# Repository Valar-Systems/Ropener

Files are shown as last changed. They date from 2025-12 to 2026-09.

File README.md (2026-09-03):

# The Ropener: Silent drape runners

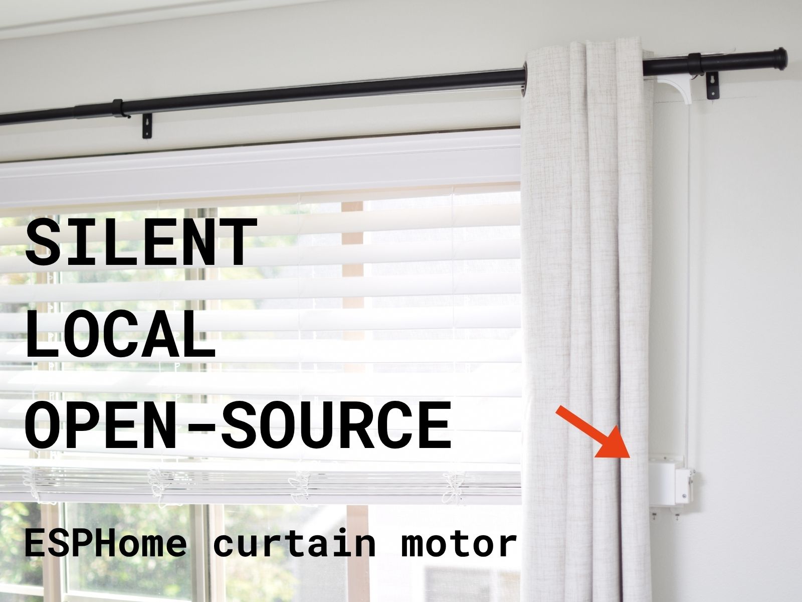
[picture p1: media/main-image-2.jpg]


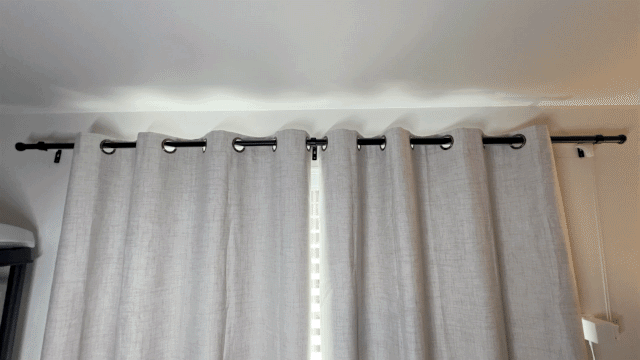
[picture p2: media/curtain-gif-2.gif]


Thanks for the great idea, Nadine!

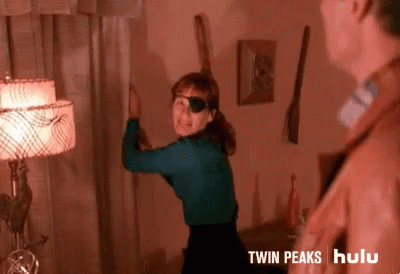
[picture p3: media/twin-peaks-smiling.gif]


The Ropener is a smart curtain opener that uses two buttons and ESPHome to open and close your curtain. Combine it with Node-RED, Home Assistant (via ESPhome) to get your curtain to open and close automatically.

## Kits
This device was created by me, [Daniel Frenkel](https://github.com/daniel-frenkel), and I have a small US-based shop that you can purchase a [hardware kit](https://valarsystems.com/products/ropener) from. If it's sold out, **PLEASE** sign up to the waitlist. It's the only indication I have to make more. If you don't, then I'll **NEVER** make more.

Without the kit, it's a pain to source all the parts, and costs a lot more because you'll be forced to buy 100 screws (when you only need 2) and 100ft of rope (when you only need 30ft) at a time.

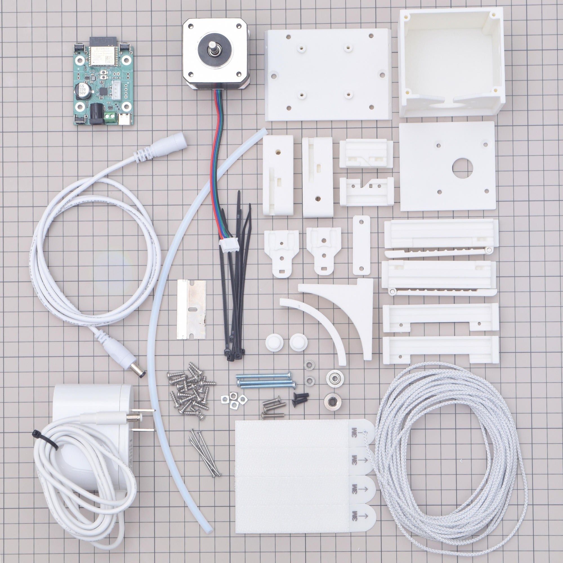
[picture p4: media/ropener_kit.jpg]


## How it works

The motor is attached to your wall just behind one of the curtains

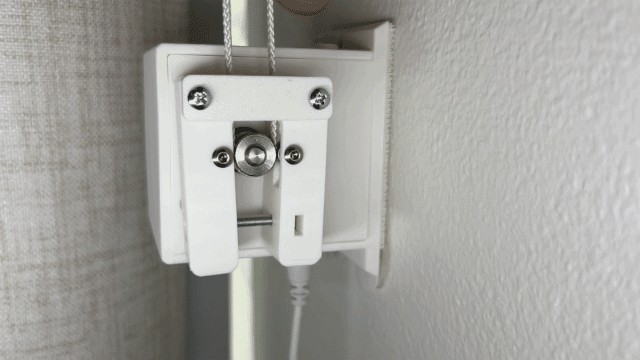
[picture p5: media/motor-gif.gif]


There is a carriage attached to the back of each curtain panel. A string runs through each carriage and through the motor which pulls it open and close.

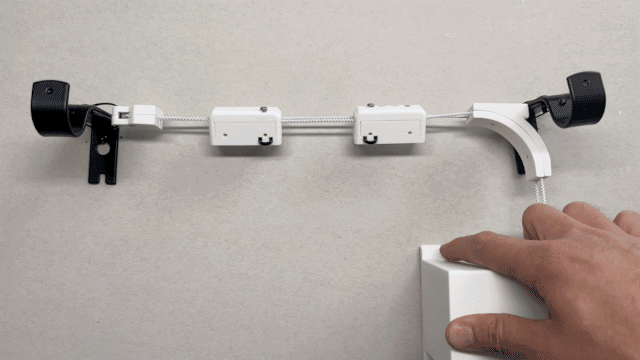
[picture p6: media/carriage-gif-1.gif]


At the heart of the device is our custom PCB which uses an ESP32 and Trinamic TMC2209 stepper driver. The motor is dead silent.

The latest **v1.1** hardware revision uses a smaller-diameter MK8 drive gear that boosts the pull strength from 11 lb to **15 lb**, swaps to a single larger bearing per arm (fewer parts), and uses pre-cut PTFE tubes. See the [hardware notes](hardware/README.md) for details.

## Will it work on your curtains?

This works on the following curtains:

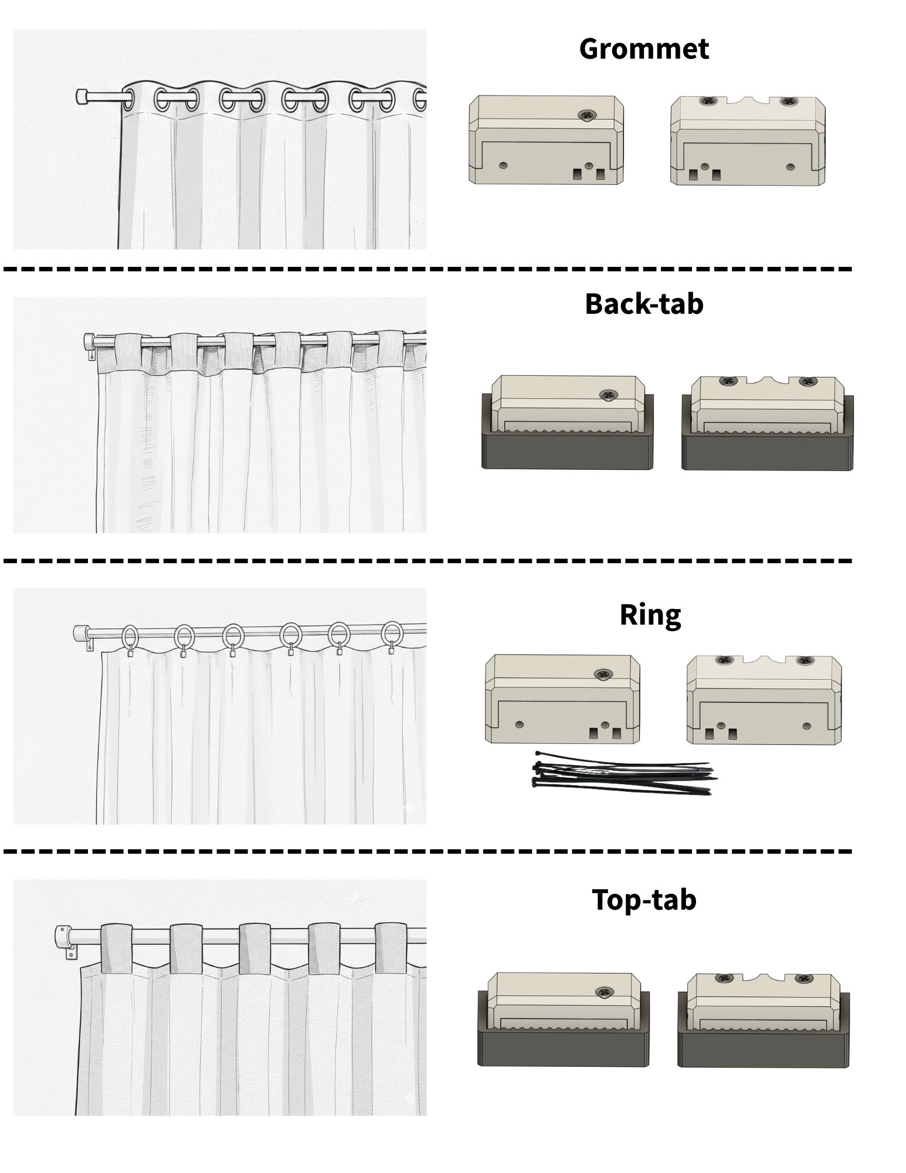
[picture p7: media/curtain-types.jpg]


## How to build it

The build guide can be found [here](https://youtu.be/uowt6jLxNso).

The installation guide can be found [here](https://youtu.be/p8078ezLZHw).

We've created a hardware kit that includes everything. If you source the parts individually, it will cost 5X more just because all of the hardware need to purchased in bulk from places like McMaster-Carr. You may optionally 3D print your parts.

* Total print time: ~9 hours (You can also purchase the 3D prints)
* Total assembly time: ~20 minutes

[Link to kit](https://valarsystems.com/products/ropener)

## How to 3D print it

The current revision is **v1.1**. Open the print plate at [hardware/plastics/v1.1/platter-all-v1.1.3mf](hardware/plastics/v1.1/platter-all-v1.1.3mf), or print the individual `.step` files in that folder. The earlier [v1.0](hardware/plastics/v1.0) files remain for anyone who already built one.

## How to install it

Either use the included foam mounting squares (recommended), small nails (for drywall only), or two screws/anchors. It's very easy to install.

## Sending commands

ESPHome is the preferred way of controlling it. Pair it with Matterbridge and you can control your curtains with Alexa, Apple, and Google Home.

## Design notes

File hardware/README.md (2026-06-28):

# What's new in v1.1
The current hardware revision is **v1.1**. Print from [`hardware/plastics/v1.1`](plastics/v1.1) (the [v1.0](plastics/v1.0) files remain for anyone who already built one).

- **Stronger pull (11 lb → 15 lb)** — a smaller-diameter **MK8** drive gear replaces the MK7.
- **Fewer parts** — each arm now uses **one larger 633ZZ bearing (3 × 13 × 5 mm)** instead of two small bearings.
- **Pre-cut PTFE tubes** — tubes now ship pre-cut to **10 / 40 / 70 mm** (two of each), so there's no measuring or razor-cutting during the build.

The plastics changed slightly to suit the new tube lengths; otherwise assembly is the same.

# Instructions
Image build guide can be found [here](https://canva.link/tmpoyau5pfkddx3).\
Video build guide can be found [here](https://youtu.be/uowt6jLxNso).\
Video installation guide can be found [here](https://youtu.be/p8078ezLZHw).

# Parts
You can purchase a kit [here](https://valarsystems.com/products/ropener) that includes all of these parts.\
Or you can source the parts below.

| Item  | Quantity|
| ---|---|
| [PCB](https://valarsystems.com/products/val3000)|1|
| [Motor](https://valarsystems.com/products/stepper-motor-nema-17)|1|
| [24V 1.5A Power adapter](https://valarsystems.com/products/power-adapter)|1|
| [Cable extension](https://valarsystems.com/products/barrel-plug-extension-cable?variant=43389605609531)|As needed|
| [3M Command Strips](https://valarsystems.com/products/3m-command-strips)|4|
| [Rope](https://valarsystems.com/products/rope)|30ft|
| [PTFE Tubing (pre-cut: 2×10mm, 2×40mm, 2×70mm)](https://valarsystems.com/products/ptfe-tube)|6|
| [M3 Square Nut](https://valarsystems.com/products/m3-square-nut)|4|
| [M3x35mm Button Head Screw](https://valarsystems.com/products/m3-x-35mm-button-head-screw)|3|
| [V-Groove Pulley](https://valarsystems.com/products/v-groove-pulley)|1|
| [M3x10mm Flat Head Screw](https://valarsystems.com/products/m3-x-35mm-button-head-screw-copy)|2|
| [M3x15mm Button Head Screw](https://valarsystems.com/products/m3-x-10mm-thread-forming-screw-copy)|3|
| [633ZZ Bearing (3×13×5mm)](https://valarsystems.com/products/bearing)|2|
| [MK8 Drive Gear](https://valarsystems.com/products/ropener-drive-gear)|1|
| [Zip Tie](https://valarsystems.com/products/zip-tie)|4|
| [M3x10mm Thread Forming Screw](https://valarsystems.com/products/m3-x-10mm-thread-forming-screw)|23|

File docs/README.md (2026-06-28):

# Docs

This folder holds the **sources** for the Ropener documentation and the scripts
that render them. The rendered deliverables (`.docx` / `.pdf` / `.png`) are
**generated artifacts** — they are written to `dist/` and are **not** tracked in
git (see the root `.gitignore`). The print-ready finals are published to the
Valar Systems Google Drive, the same way firmware binaries go to GitHub Releases.

## What's tracked (source)

| File | Role |
| --- | --- |
| `BOM-V2.0.md` | Bill of Materials, human-readable source (also linked from the wiki) |
| `Ropener-User-Guide.md` | Markdown copy of the user guide |
| `make_bom.py` | Renders the BOM `.docx` |
| `make_box_insert.py` | Renders the box-insert `.png` + `.pdf` |
| `make_user_guide.py` | Renders the user-guide `.docx` |
| `valar-logo-black.png`, `valar-logo-white.png` | Brand assets used by the generators |
| `wiki-*.md` | Mirror of the GitHub wiki pages |

## What's generated (in `dist/`, gitignored)

- `Ropener Bill of Materials.docx`
- `Ropener Box Insert.png` / `Ropener Box Insert.pdf`
- `Ropener User Guide.docx`
- `Ropener Bill of Materials.pdf`, `Ropener User Guide.pdf` (see Word step below)

## Regenerating

```sh
pip install python-docx pillow segno      # one-time
py -3.13 make_bom.py
py -3.13 make_box_insert.py
py -3.13 make_user_guide.py
```

Each script writes into `dist/`.

- **Box insert** is fully reproducible on any platform — the script emits both
  the `.png` and the `.pdf` directly.
- **BOM** and **User Guide** scripts emit only `.docx`. To produce the matching
  `.pdf`, open the `.docx` in **Microsoft Word** and *Save As → PDF* (requires
  Windows + Word; this step is not reproducible in CI).

Then upload the finals from `dist/` to the Valar Drive.

## Known caveat

The user-guide content currently lives in **two** places: inline in
`make_user_guide.py` and again in `Ropener-User-Guide.md`; `make_bom.py`
likewise duplicates `BOM-V2.0.md` by hand. Keep them in sync when editing. The
proper long-term fix is to have the generators read the markdown directly so
there is a single source of truth.

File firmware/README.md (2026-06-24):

# ESPHome YAML

#### Warning:
***Do not use StallGuard*** unless you set it up correctly. StallGuard is finicky and requires exact parameters. I am working on creating preset settings that should fix this, but for now, do not use it. It is also not required for this device to work properly.

After pasting the YAML into ESPHome, ***only*** change the device names. Do not change anything else.

```
esphome:
  name: ropener-bedroom-1                 # change this name
  friendly_name: "Ropener Bedroom 1"      # change this name
```

After uploading, go to the settings page here and update the things in red.

settings

The most important settings are the centimeters (this sets the max travel distance) and the motor direction.

IRUN sets the motor current. 31 is the max value. The downside of a higher setting is that the driver will heat up quickly and will shut down when too hot. Use as low of a value as possible. A value too low however will make the motor too weak and it will stall. It's best to experiment to find the lowest value possible while not stalling the motor. Stalling does not damage the motor.

Be sure the state is correct in the settings when the device is moving.

state

Once everything is set, you have to manually set the home position. There are 3 ways to do this.

1. In the settings, under Diagnostic, there is a "Start-Stop Homing" button. Press it and it will begin to close the curtain. Press it again to stop the curtain. This will now be the zero position.
2. Tap the left button (Button 1) on the motor **seven times quickly**. It will begin to close the curtain. Press either button once to stop it — this stops the motor and sets the position to zero.
3. Move the curtain to the spot you want to call "closed" (use hold-to-run, below), then **hold both buttons at once for 3 seconds**. The current position is set as home (0) without driving into the end stop.

It should now be homed to position 0, and when you press the open button, it should travel the centimeters distance you set in the settings.

## Button controls

| Gesture | Action |
| --- | --- |
| Tap Button 1 (close) | Close the curtain |
| Tap Button 2 (open) | Open the curtain |
| Press & hold Button 1 | Close **only while held** — stops the instant you let go, and stops automatically at the closed end |
| Press & hold Button 2 | Open **only while held** — stops the instant you let go, and stops automatically at the open end |
| Tap Button 1 seven times quickly | Start homing |
| Hold both buttons for 3 seconds | Set the current position as home (0) |
| Any press while the curtain is moving | Stops it instantly |
| Any press while homing | Stops it and sets the position to zero |

Hold-to-run is the child- and elderly-friendly mode: the curtain only moves while you keep the button pressed, so it can't run on its own into a person or a cord, and it never drives past the open or closed ends.

## Updating the firmware

Two ways to update:

- **Over the air, from the device:** open the settings page and, under Diagnostics, press **"Update Firmware (GitHub)"**. The device downloads the latest release for its model straight from GitHub, flashes itself, and reboots — no computer needed. (Requires an internet connection.)
- **Manually:** download the `*.ota.bin` (for a device already on your network) or `*.factory.bin` (for a fresh USB flash) for your model from the [latest release](https://github.com/Valar-Systems/Ropener/releases/latest) and upload it as before.

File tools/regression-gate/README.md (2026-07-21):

# Firmware regression gate

Two diffs between the **old** and **new** resolved firmware config. Run both
before every release. A clean `esphome compile` is necessary but **not
sufficient** — it proves the YAML is valid, not that the firmware still behaves
the same.

## Why the behaviour gate exists

v2.7.0 rewired the Ropener onto `valar-core` as a remote package. The entity
gate passed perfectly: no entity dropped, renamed, or retyped. It shipped.

But the product's `on_stall` handler had been silently replaced by
`valar-core`'s default. Two live bugs resulted:

- the device wedged in `HOMING` forever after any home (killing the button
  gestures and the schedule, both of which guard on `global_state`), and
- **every** stall zeroed the position, so a curtain snagging mid-travel
  silently redefined that point as home.

No entity name changed, so nothing caught it. The behaviour gate diffs the
*automation bodies* — `on_stall`, `on_press`/`on_click`/`on_release`, script
bodies, `on_boot`, intervals, `*_action`, lambdas — anchored to stable
identities rather than list positions.

It also caught an unrelated change in the same release: the `Motor Direction`
option string `"Reversed ↺"` had lost its glyph, which would have broken any
Home Assistant automation selecting it by value.

## Usage

```sh
# 1. Resolve both configs (from a checkout of each version)
esphome config firmware/VAL3100/Ropener-VAL3100.yml > /tmp/old-3100.yaml
esphome config firmware/VAL3100/Ropener-VAL3100.yml > /tmp/new-3100.yaml

# 2. Diff them
python tools/regression-gate/gate.py /tmp/old-3100.yaml /tmp/new-3100.yaml

# 3. Inspect anything it flags
python tools/regression-gate/gate.py /tmp/old-3100.yaml /tmp/new-3100.yaml \
    --detail on_stall
```

Exit code `0` = both gates clean, `1` = something differs. **A difference is not
automatically a failure** — additions and refactors are often intended. The
gate's job is to guarantee nothing changes *unnoticed*. Every flagged line must
be explained in the release notes.

Run it for **each board** (VAL3000 and VAL3100); they share a product layer but
resolve differently.

Requires `pyyaml` — use the interpreter ESPHome is installed under.

## Known-benign differences after the valar-core rewire

Expected when diffing a pre-rewire release (≤ v2.6.4) against a rewired one:

| Anchor | Why |
|---|---|
| 7 diagnostic entities added | `valar-core` shared diagnostics (Restart, Uptime, WiFi Signal, ESP Internal Temperature, IP/SSID/MAC) |
| `esphome:on_boot` split 600 / 400 / -100 | core / product / scheduling layers; relative order preserved |
| `script:schedule_open`, `script:schedule_close` | scheduling-mixin contract; the `global_state != 3` homing guard moved into these scripts |
| `datetime:Open Time`/`Close Time` `on_time`, `interval:60s` | now call the schedule scripts instead of inlining `cover.open`/`cover.close` |

Anything **outside** this table needs justification before release.

## Before Glasscalibur

This tool should move to `valar-motion` so both products share one copy rather
than duplicating it — same rule as the firmware itself. Glasscalibur's overrides
(limit switches, TMP1075 thermal cutoff, LIS2DH12 tamper, buzzer) carry the same
silent-replacement risk as `on_stall` did here, and there a dropped thermal
cutoff or tamper handler is a safety regression, not a UX one.

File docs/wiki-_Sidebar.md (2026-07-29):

<p align="center">
  <a href="Home"><b>Ropener</b></a><br/>
  <a href="https://valarsystems.com/products/ropener">🛒 Buy a kit</a>
</p>

---

**Getting Started**
- [Home](Home)

**Build & Install**
- [Build Guide](Build-Guide)
- [Installation Guide](Installation-Guide)
- [Bill of Materials](https://github.com/Valar-Systems/Ropener/blob/main/docs/BOM-V2.0.md)

**Firmware & Use**
- [Firmware Guide](Firmware-Guide)
- [User Guide](User-Guide)

---

**Links**
- [GitHub Repo](https://github.com/Valar-Systems/Ropener)
- [Report an Issue](https://github.com/Valar-Systems/Ropener/issues)
- [valarsystems.com](https://valarsystems.com)

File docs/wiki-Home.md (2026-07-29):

<p align="center">
  Ropener automated curtain opener
</p>

<h1 align="center">Ropener</h1>
<p align="center"><b>The dead-silent Wi-Fi curtain opener.</b><br/>
Control it from its built-in web page, the on-device buttons, or your smart home (Home Assistant, Alexa, Apple Home, Google Home).</p>

<p align="center">
  <a href="https://valarsystems.com/products/ropener"><b>🛒 Buy a kit</b></a> &nbsp;·&nbsp;
  <a href="Build-Guide"><b>🔧 Build it</b></a> &nbsp;·&nbsp;
  <a href="User-Guide"><b>📖 User Guide</b></a>
</p>

---

## Quick Start

| Step | What you'll do | Guide |
| :--: | :--- | :--- |
| **1** | Get the parts — buy a kit or 3D-print the plastics. | [🛒 Kit](https://valarsystems.com/products/ropener) · [📋 BOM](https://github.com/Valar-Systems/Ropener/blob/main/docs/BOM-V2.0.md) |
| **2** | Build it (~20 min). | [Build Guide](Build-Guide) |
| **3** | Install it on your curtains. | [Installation Guide](Installation-Guide) |
| **4** | Flash & configure the firmware. | [Firmware Guide](Firmware-Guide) |
| **5** | Use it every day. | [User Guide](User-Guide) |

> 💬 Having trouble? [Open an issue](https://github.com/Valar-Systems/Ropener/issues) or improve this wiki.

---

## Why Ropener

- **🔇 Silent** — Trinamic TMC2209 stepper driver.
- **📶 Wi-Fi built in** — control from any browser at `http://ropener-XXXXXX.local`, no cloud needed.
- **🏠 Smart-home ready** — Home Assistant via ESPHome; Alexa, Apple & Google via Matterbridge.
- **⏰ Scheduling** — set daily open/close times, or any position in between.
- **🛠️ Easy install** — foam mounting squares mean no holes in the wall.

---

<p align="center">
  <a href="https://valarsystems.com">Valar Systems</a> · <a href="https://valarsystems.com/products/ropener">Buy a kit</a> · <a href="https://github.com/Valar-Systems/Ropener">Repo</a> · <a href="https://github.com/Valar-Systems/Ropener/issues">Issues</a>
</p>

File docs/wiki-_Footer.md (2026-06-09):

<p align="center">
  <a href="https://valarsystems.com"><b>Valar Systems</b></a> ·
  <a href="https://valarsystems.com/products/ropener">🛒 Buy a kit</a> ·
  <a href="https://github.com/Valar-Systems/Ropener">GitHub Repo</a> ·
  <a href="https://github.com/Valar-Systems/Ropener/issues">💬 Report an issue</a>
</p>

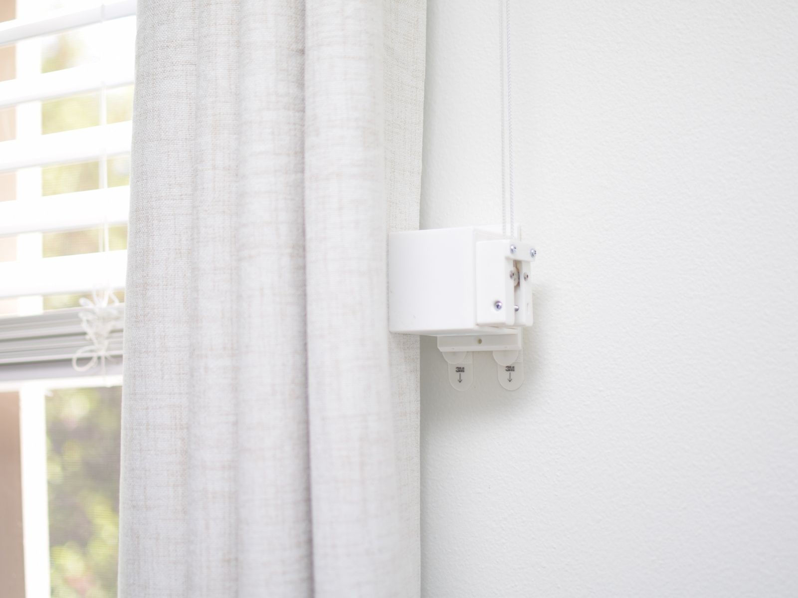
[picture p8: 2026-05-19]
media/ropener-closeup.jpg

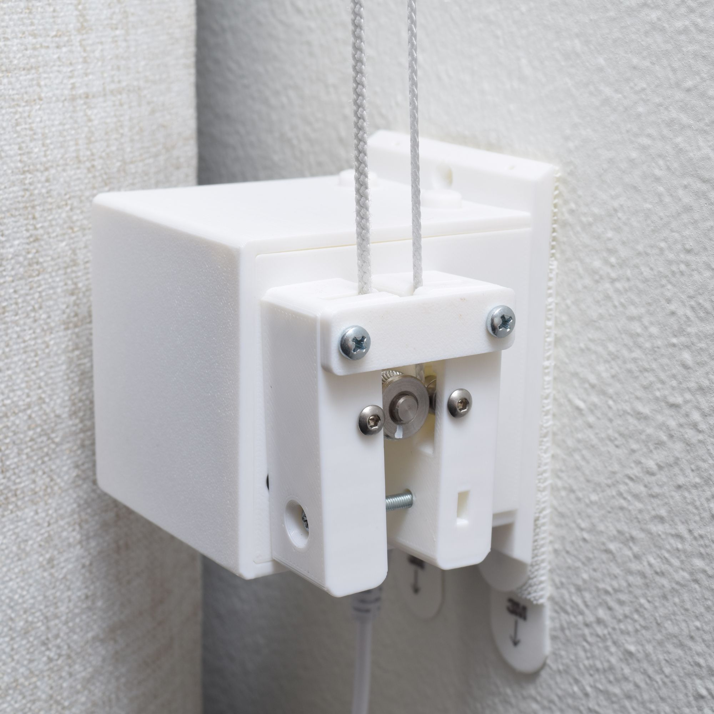
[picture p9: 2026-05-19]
media/ropener-closeup-2.jpg

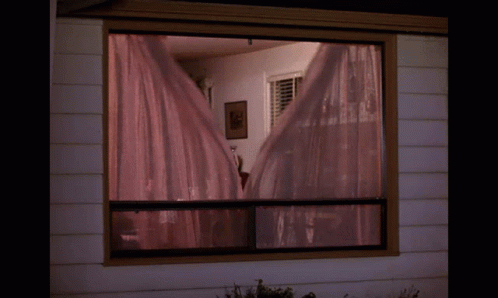
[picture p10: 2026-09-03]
media/twin-peaks-nadine-drapes.gif

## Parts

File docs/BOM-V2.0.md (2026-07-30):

# BOM V2.0

> Reflects the current **v1.2.1** hardware. Notable changes since v1.0: a smaller-diameter **MK8** drive gear (pull strength 11 lb → 15 lb), **one larger 633ZZ bearing per arm** instead of two small bearings, **pre-cut PTFE tubes** (no razor-cutting), **foam mounting squares** in place of adhesive command strips, and a **24 V 1.5 A** power adapter. Quantities are per unit. Every purchasable part links to the [Valar Systems store](https://valarsystems.com).

## Body Assembly

| Part | Qty | Description |
| :--- | :---: | :--- |
| VAL3000 PCB | 1 | [Custom ESP32 + Trinamic TMC2209 PCB](https://valarsystems.com/products/val3000). [Open-hardware design](https://github.com/Valar-Systems/VAL3000). |
| NEMA 17 motor, 48 mm body | 1 | [NEMA 17, 48 mm body](https://valarsystems.com/products/stepper-motor-nema-17) — a shorter one also works. |
| 24 V 1.5 A power adapter | 1 | [24 V 1.5 A, 5.5 × 2.1 mm barrel plug](https://valarsystems.com/products/power-adapter). |
| Extension cable | 1 | [Straight barrel-plug extension](https://valarsystems.com/products/barrel-plug-extension-cable). |
| M3 × 10 mm screw, self-tapping | 8 | [Thread-forming screw](https://valarsystems.com/products/m3-x-10mm-thread-forming-screw). |
| M3 × 35 mm screw, button head | 3 | [Arm assembly screws](https://valarsystems.com/products/m3-x-35mm-button-head-screw). |
| M3 square nut | 3 | [Square nut](https://valarsystems.com/products/m3-square-nut) — arm nuts (2) + clamp nut (1). |
| M3 × 15 mm screw, button head | 3 | [Arm screws (2) + curtain-pulley screw (1)](https://valarsystems.com/products/m3-x-15mm-button-head-screw). |
| M3 × 10 mm screw, flat head | 2 | [Flat-head screw](https://valarsystems.com/products/m3-x-10mm-flat-head-screw). |
| Gear | 1 | MK8, 5 mm bore / 9 mm OD — [buy](https://valarsystems.com/products/ropener-drive-gear). |
| Bearing | 2 | 633ZZ, 3 mm × 13 mm × 5 mm — [buy](https://valarsystems.com/products/633zz-bearing). |

## Curtain Assembly

| Part | Qty | Description |
| :--- | :---: | :--- |
| PTFE tubing, 3 mm ID × 5 mm OD (pre-cut) | 6 | 2 × 10 mm, 2 × 40 mm, 2 × 70 mm — [buy](https://valarsystems.com/products/ptfe-tube). |
| M3 × 10 mm screw, self-tapping | 14 | [Thread-forming screw](https://valarsystems.com/products/m3-x-10mm-thread-forming-screw). |
| M3 square nut | 1 | [Curtain-pulley nut](https://valarsystems.com/products/m3-square-nut). |
| Zip tie | 4 | Small, 2–3 mm wide. One for the motor-side rope elbow, one for the far-side pulley, and two for attaching carriages to ring curtains (one per carriage) — [buy](https://valarsystems.com/products/zip-tie). |
| V623ZZ pulley | 1 | 3 × 12 × 4 mm — [V-groove pulley](https://valarsystems.com/products/v-groove-pulley). |
| Rope | 1 | 1.6 mm diameter — [buy](https://valarsystems.com/products/rope). |

> **Carriages:** the standard build uses **two** carriages (one with a single top screw, one with two). How many carriages a multi-panel curtain needs is not documented yet — **TODO**.

### Mounting Hardware

| Part | Qty | Description |
| :--- | :---: | :--- |
| Foam mounting square, 1" | 5 | Double-sided; **five squares per unit**. Wipe the surface clean and dry, then press firmly — [buy](https://valarsystems.com/products/foam-mounting-squares). |

## Assembly Tools Required

| Part | Qty | Description |
| :--- | :---: | :--- |
| Screwdriver, Phillips No. 1 | 1 | [Phillips No. 1](https://valarsystems.com/products/phillips-no-1-screw-driver). |
| Hex driver, 2 mm | 1 | For the M3 button-head screws — [2 mm hex driver](https://valarsystems.com/products/allen-wrench-2mm). |
| Hex driver, 1.5 mm | 1 | For the MK8 drive-gear set screw — [1.5 mm hex driver](https://valarsystems.com/products/allen-wrench-1-5mm). |

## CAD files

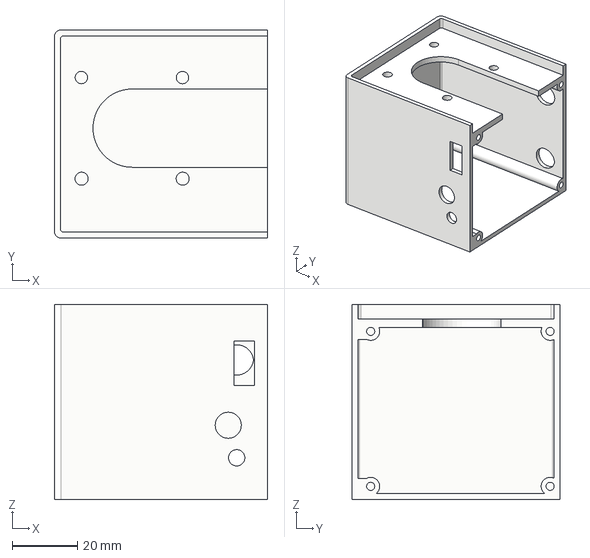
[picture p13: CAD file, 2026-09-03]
hardware/plastics/v1.2.2/body/main-body.step
65.3 x 63.8 x 59.8 mm

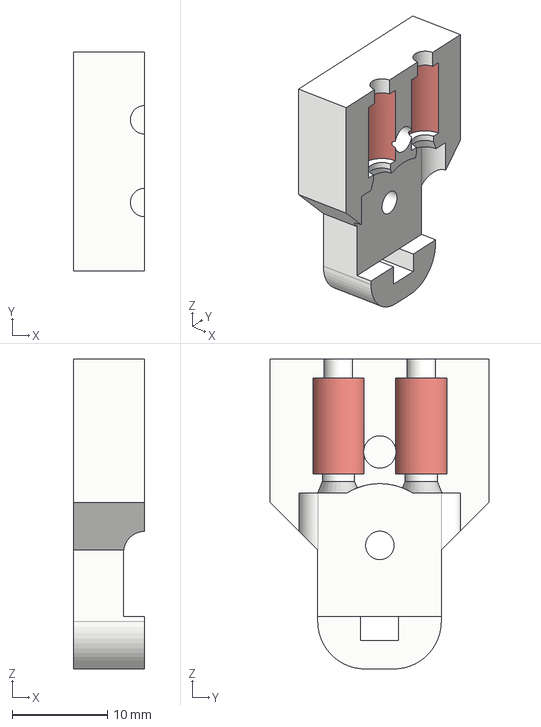
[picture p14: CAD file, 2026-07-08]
hardware/plastics/v1.2.2/curtain/end-pulley-top.step
7.50 x 23.0 x 32.6 mm

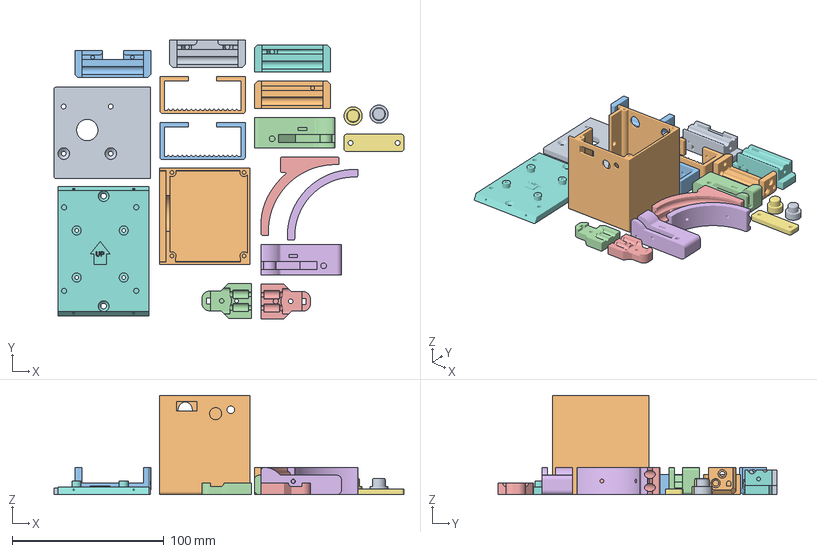
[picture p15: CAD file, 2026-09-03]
hardware/plastics/v1.2.2/platter-all-v1.2.2.3mf
230.4 x 183.5 x 65.3 mm
button x 2
back-tab-clamp-right
back-tab-clamp-left
arm-right
rope-elbow-top
arm-left
arm-connector
carriage-bottom-left
carriage-bottom-right
carriage-top-left
carriage-top-right
end-pulley-bottom
end-pulley-top
rope-elbow-bottom
wall-plate.step
outer-body.step
main-body.step

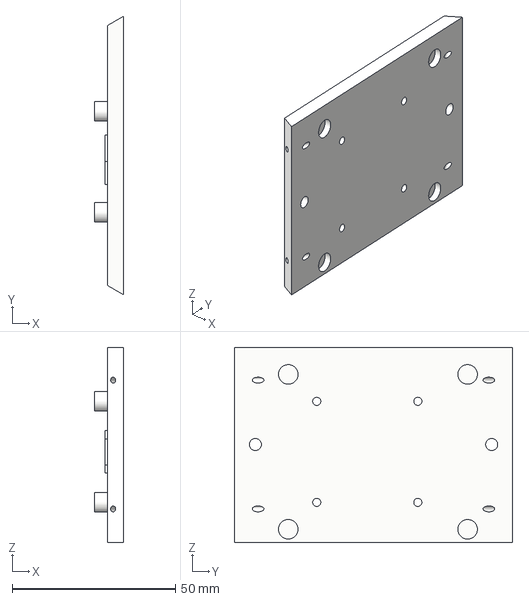
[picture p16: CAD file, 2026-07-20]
hardware/plastics/v1.2.2/body/wall-plate.step
8.90 x 85.4 x 59.8 mm

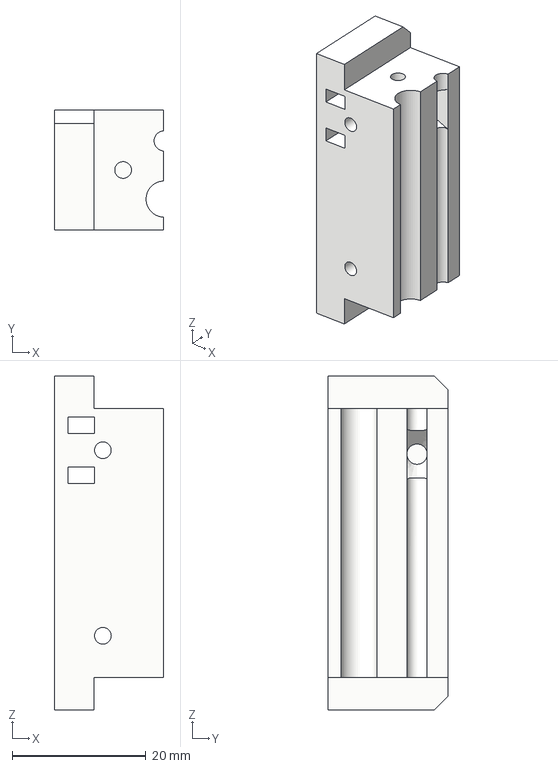
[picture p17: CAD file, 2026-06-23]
hardware/plastics/v1.2.2/curtain/carriage-bottom-left.step
16.3 x 17.9 x 50.0 mm

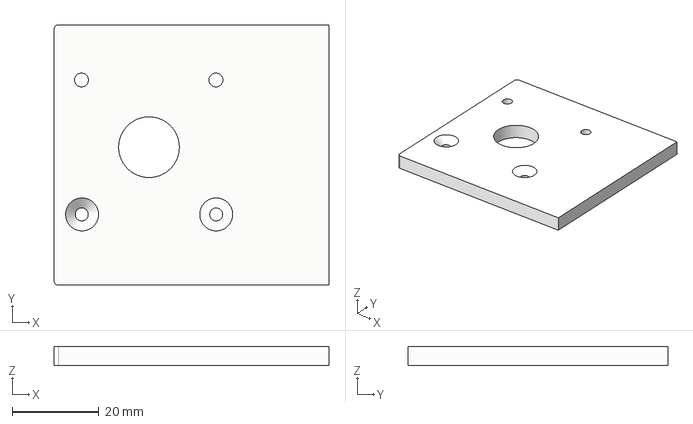
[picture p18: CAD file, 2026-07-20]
hardware/plastics/v1.2.2/body/outer-body.step
63.4 x 60.0 x 4.45 mm

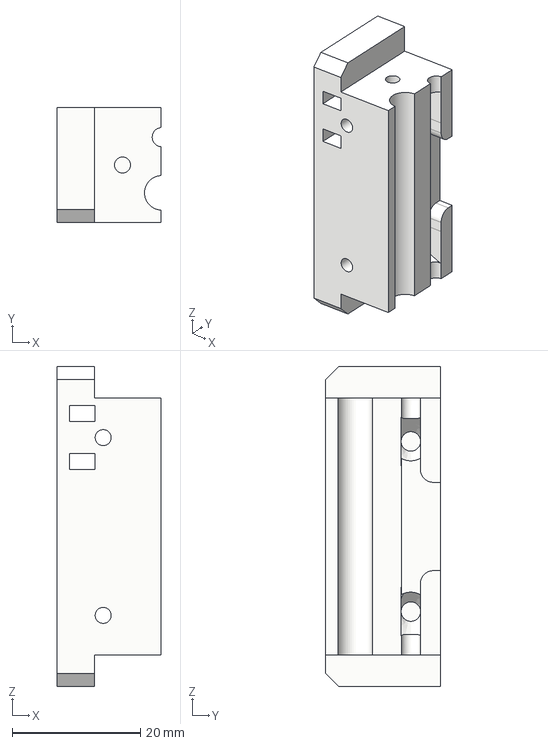
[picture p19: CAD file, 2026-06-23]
hardware/plastics/v1.2.2/curtain/carriage-bottom-right.step
16.3 x 17.9 x 50.0 mm

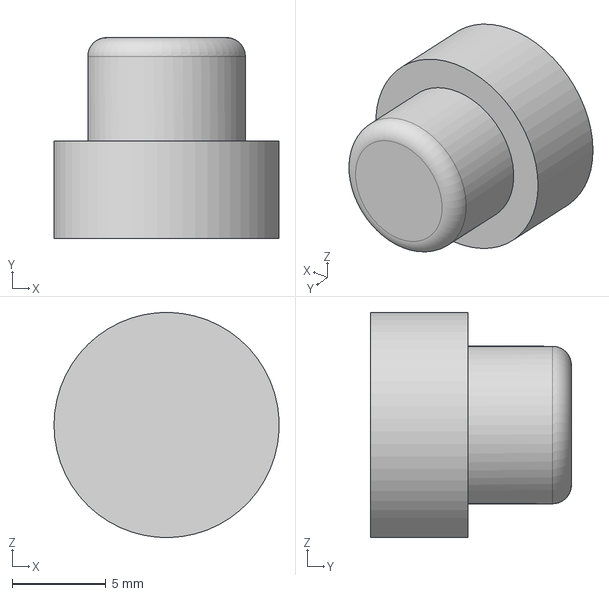
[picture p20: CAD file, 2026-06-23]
hardware/plastics/v1.2.2/body/button.step
12.0 x 10.7 x 12.0 mm

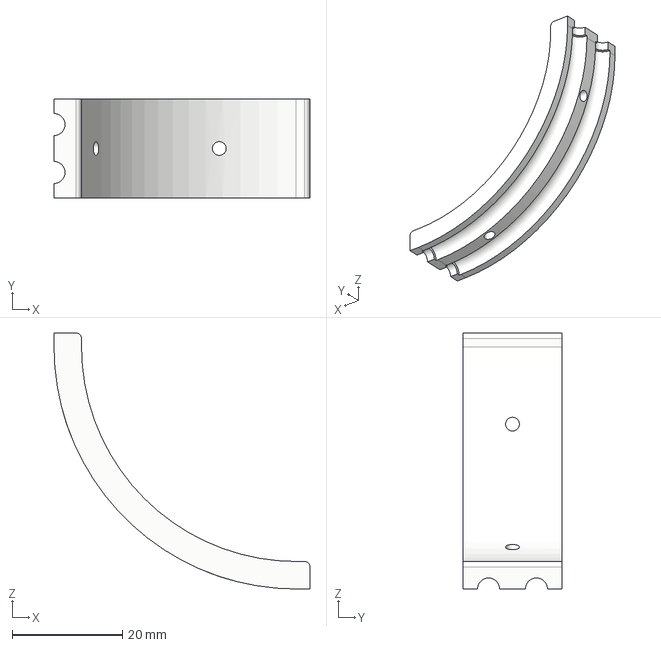
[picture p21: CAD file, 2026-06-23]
hardware/plastics/v1.2.2/curtain/rope-elbow-bottom.step
46.5 x 17.9 x 46.5 mm

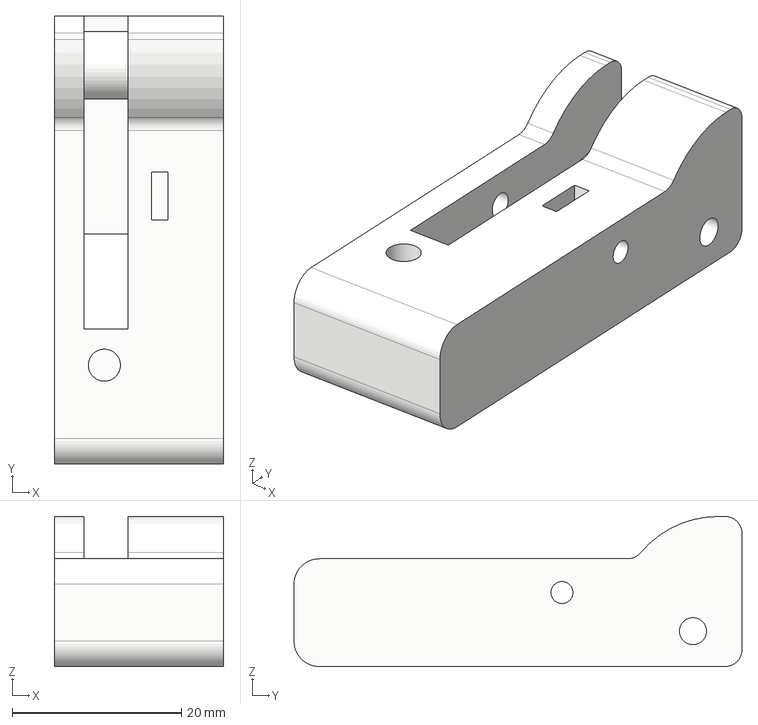
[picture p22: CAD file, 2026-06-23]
hardware/plastics/v1.2.2/body/arm-left.step
20.0 x 53.0 x 17.8 mm

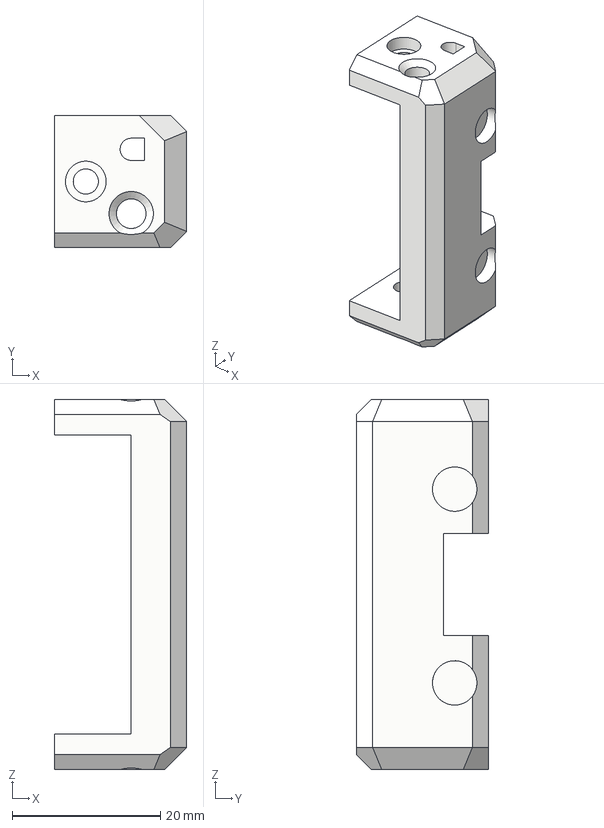
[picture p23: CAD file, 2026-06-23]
hardware/plastics/v1.2.2/curtain/carriage-top-right.step
17.9 x 17.9 x 50.0 mm

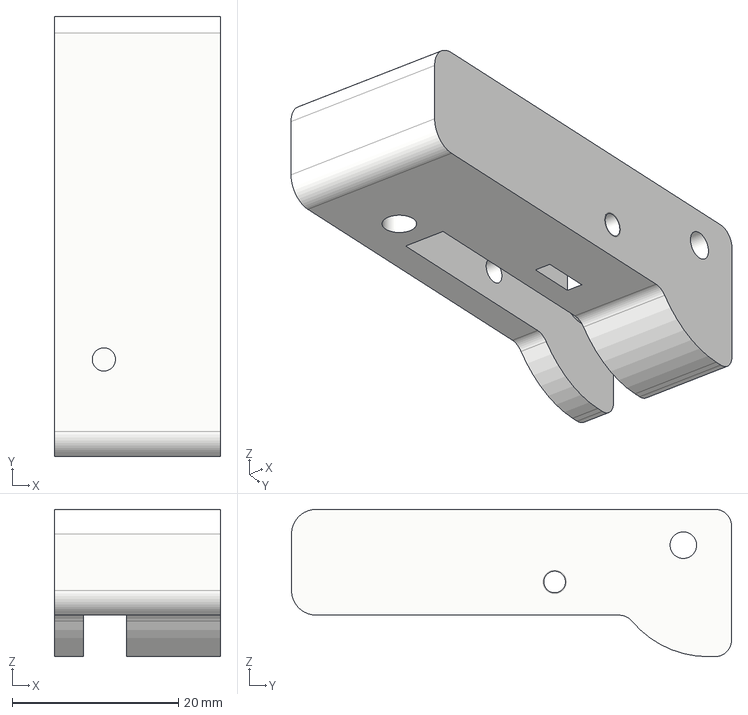
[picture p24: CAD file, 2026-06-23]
hardware/plastics/v1.2.2/body/arm-right.step
20.0 x 53.0 x 17.8 mm

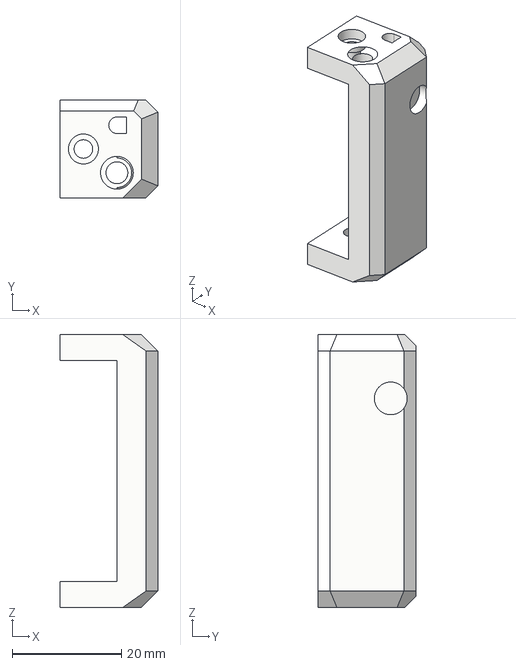
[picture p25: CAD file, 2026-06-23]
hardware/plastics/v1.2.2/curtain/carriage-top-left.step
17.9 x 17.9 x 50.0 mm

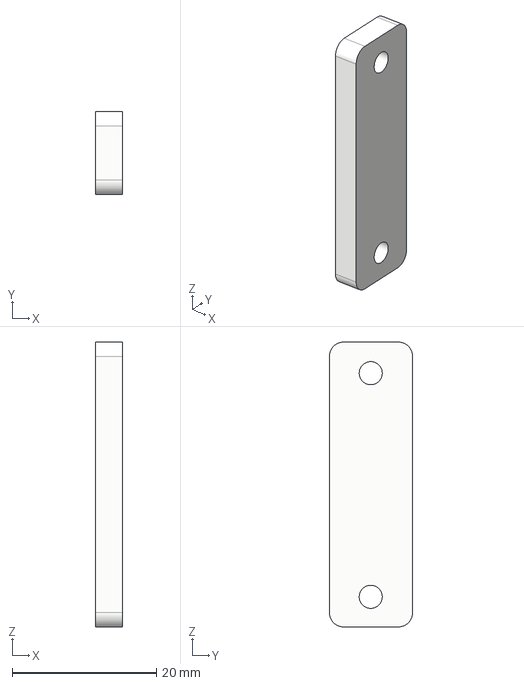
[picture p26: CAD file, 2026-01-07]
hardware/plastics/v1.2.2/body/arm-connector.step
3.70 x 11.5 x 39.5 mm

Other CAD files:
hardware/plastics/v1.2.2/curtain/rope-elbow-top.step
hardware/plastics/v1.2.2/curtain/end-pulley-bottom.step
hardware/plastics/v1.2.2/curtain/tube-cut-tool.step
hardware/plastics/v1.2.2/curtain/carriage-clamp-right.step
hardware/plastics/v1.0.0/body/arm-left.step
hardware/plastics/v1.0.0/body/arm-right.step
hardware/plastics/v1.0.0/body/main-body.step
hardware/plastics/v1.0.0/body/outer-body.step
hardware/plastics/v1.0.0/body/wall-plate.step
hardware/plastics/v1.0.0/curtain/carriage-bottom-left.step
hardware/plastics/v1.0.0/curtain/carriage-bottom-right.step
hardware/plastics/v1.0.0/curtain/carriage-top-left.step
hardware/plastics/v1.0.0/curtain/carriage-top-right.step
hardware/plastics/v1.0.0/curtain/end-pulley-bottom.step
hardware/plastics/v1.0.0/curtain/end-pulley-top.step
hardware/plastics/v1.0.0/curtain/rope-elbow-bottom.step
hardware/plastics/v1.0.0/curtain/rope-elbow-top.step
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

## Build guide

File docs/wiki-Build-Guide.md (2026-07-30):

# 🔧 Build Guide

<p align="center">
  Ropener kit parts laid out
</p>

Assembling a Ropener takes about **20 minutes** with three common hand tools — no soldering. It comes together in three stages: the **motor body**, the **curtain-rail carriages**, and **attaching it to your curtains**. Follow whichever guide below suits you — they all cover the same build.

> 🆕 **Current hardware — v1.2.1.** Notable changes since v1.0:
> - **Stronger pull (11 lb → 15 lb)** from a smaller-diameter **MK8** drive gear (replaces the MK7).
> - **One larger 633ZZ bearing (3 × 13 × 5 mm) per arm** instead of two small bearings.
> - **Pre-cut PTFE tubes** (10 / 40 / 70 mm) — no measuring or razor-cutting.
>
> Print from [`hardware/plastics/v1.2.1`](https://github.com/Valar-Systems/Ropener/tree/main/hardware/plastics/v1.2.1). Earlier revisions remain in the repo for anyone who already built one.

## How to build

| Guide | Best for |
| :-- | :-- |
| 🖼️ **[Illustrated print guide](https://canva.link/tmpoyau5pfkddx3)** | A diagram for every screw — follow along step by step |
| 🎬 **[Video walkthrough](https://www.youtube.com/watch?v=uowt6jLxNso)** | The big picture and the fiddly parts in motion |
| 📝 **[Written steps](#motor-body-assembly)** (on this page) | Quick reference and searching |

> 💬 **Trouble with anything?** Email Daniel at **daniel@valarsystems.com**, or [open an issue](https://github.com/Valar-Systems/Ropener/issues).

<!--
  IMAGES: the step figures from "Ropener DIY guide.pdf" still need to be exported to
  media/build-guide/ and embedded where the <!-- 📷 ... --> comments below mark them.
  Suggested filenames are given in each comment.
-->

---

## Contents

1. [Before you start](#before-you-start)
2. [Bill of materials](#bill-of-materials)
3. [Curtain compatibility](#curtain-compatibility)
4. [Motor body assembly](#motor-body-assembly)
5. [Curtain rail assembly](#curtain-rail-assembly)
6. [Attaching to your curtains](#attaching-to-your-curtains)
7. [Rope routing and tensioning](#rope-routing-and-tensioning)
8. [Next steps](#next-steps)

---

## Before you start

### 🧰 Tools required

> Your kit may or may not include these — the goal is to provide them, but that may not be implemented yet.

| Tool | Size |
| --- | --- |
| Phillips screwdriver | #1 |
| Hex driver (Allen wrench) | 2 mm |
| Hex driver (Allen wrench) | 1.5 mm |

### 🛒 Optional supplies

If you have **grommet curtains**, we strongly recommend **curtain glide tape** (available on Amazon). Without it the Ropener usually will not work. If your curtains don't slide smoothly, glide tape almost always fixes it.

### 🖨️ 3D-printed parts

All plastics are printed on an FDM printer. A few parts use supports that must be removed by hand. Everything fits a **220 × 220 mm** bed, and **PLA** is fine for indoor use.

| Setting | Value |
| --- | --- |
| Layer height | 0.3 mm |
| Infill | 20%, grid |
| Supports | Yes (on some parts) |
| Total print time | ~9 hours |

### ⚙️ Firmware

Ropener runs **ESPHome** — the supported, actively maintained firmware. See the [Firmware Guide](Firmware-Guide) for flashing and updates. *(Alternative builds have existed but are unsupported; firmware contributions via pull request are welcome.)*

---

## Bill of materials

Everything the build needs is below. For the full, maintained list see the [Bill of Materials](https://github.com/Valar-Systems/Ropener/blob/main/docs/BOM-V2.0.md).

| Item | Quantity |
| --- | --- |
| VAL3000 / VAL3100 PCB | 1 |
| NEMA 17 stepper motor | 1 |
| 24 V 1.5 A power adapter | 1 |
| Cable extension | as needed |
| Foam mounting square, 1" | 5 |
| 1.6 mm rope | 30 ft |
| PTFE tubing (pre-cut: 2 × 10 mm, 2 × 40 mm, 2 × 70 mm) | 6 |
| M3 square nut | 4 |
| M3 × 35 mm button-head screw | 3 |
| V-groove pulley | 1 |
| M3 × 10 mm flat-head screw | 2 |
| M3 × 15 mm button-head screw | 3 |
| Bearing (633ZZ, 3 × 13 × 5 mm) | 2 |
| MK8 drive gear | 1 |
| Zip tie | 4 |
| M3 × 10 mm thread-forming screw | 22 |

---

## Curtain compatibility

This device works on the following curtain types.

<p align="center">
  Grommet, back-tab, ring, and top-tab curtain types
</p>

| Type | Performance | Notes |
| --- | --- | --- |
| **Back-tab** | ⭐ Excellent | Best results. |
| **Ring** | Good | May require glide tape. |
| **Grommet** | OK | Requires glide tape. |
| **Top-tab** | Likely great (untested) | Should behave like back-tab if similar. |

---

## Motor body assembly

<!-- 📷 media/build-guide/05-motor-in-housing.png — motor seated in housing, wires pointing down, two M3×10 screws -->
1. **Mount the motor.** Place the motor into the housing with the **wires pointing down**, and secure it with **two black M3 × 10 mm screws**.

<!-- 📷 media/build-guide/06a-pcb-mounted.png — PCB on wall plate with 4 thread-forming screws; 📷 06b-motor-wires.png — 4 motor wires to screw terminals (blue/red/green/black) -->
2. **Mount the PCB and wire the motor.** With the plastic **facing up**, attach the PCB to the wall plate using the **four M3 × 10 mm plastic thread-forming screws**. Then connect the **four motor wires** to the screw terminals — you may need to cut and strip the wire ends.

<!-- 📷 media/build-guide/07-wallplate-buttons.png — buttons in holes, wall plate attached with 4 screws -->
3. **Fit the buttons and close the body.** Place the buttons into their holes, then attach the wall plate to the housing using **four M3 thread-forming screws**.

<!-- 📷 media/build-guide/08-drive-pulley.png — MK8 drive gear on motor shaft, set screw tightened with 1.5 mm hex -->
4. **Attach the drive gear.** Fit the **MK8 drive gear** onto the motor shaft and secure it with its **set screw, using the 1.5 mm hex driver**. Snug it just enough to hold position — you'll fine-tune the position later before fully tightening.

<!-- 📷 media/build-guide/09-arms.png — arm with M3×15mm button head (red), one 633ZZ bearing (green), M3 square nut (orange) -->
5. **Assemble the two arms.** Each arm uses an **M3 × 15 mm button-head screw**, **one 633ZZ bearing (3 × 13 × 5 mm)**, and an **M3 square nut**. **On one of the two arms, also seat a third M3 square nut into its pocket now** — that pocket is inaccessible once the arms are mated, and the **M3 × 35 mm clamp screw** in Step 8 threads into this nut to pull the arm pair against the drive pulley. Build both arms the same way.

<!-- 📷 media/build-guide/10-arms-connector.png — plastic connector + both arms on motor, 2× M3×35mm screws -->
6. **Attach the arms to the motor.** Fasten the plastic connector and **both arms** to the motor using **two M3 × 35 mm button-head screws** (two of the three arm assembly screws).

<!-- 📷 media/build-guide/11-pulley-alignment.png — drive pulley aligned with the two idler pulleys -->
7. **Check alignment.** Make sure the **drive pulley is perfectly aligned** with the two idler pulleys.

<!-- 📷 media/build-guide/12-arms-bottom.png — M3×35mm screw joining bottom of both arms (do not tighten) -->
8. **Join the bottom of the arms.** Use the third **M3 × 35 mm screw** to connect the bottom of both arms — it threads into the square nut you seated in Step 5 and clamps the arm pair against the drive pulley. **Do not tighten yet** — you'll do this after the rope is connected to the pulley.

<!-- 📷 media/build-guide/13-mounting-squares.png — foam mounting squares applied to the marked area on the back -->
9. **Apply the mounting squares.** Wipe the marked area on the back of the body clean and dry, then press the **five 1" foam mounting squares** firmly into place.

---

## Curtain rail assembly

> **Overview.** Along the rod, from one end to the other, you'll have: the **pulley**, a **carriage with one screw on top**, a **carriage with two screws on top**, and the **motor-side** anchor.

> **How many carriages?** The standard build uses **two** (one single-screw, one double-screw). How carriage count should scale as the number of curtain panels grows is not documented yet — **TODO**.

<!-- 📷 media/build-guide/15-setup-overview.png — rail layout: pulley, 1-screw carriage, 2-screw carriage, motor side -->

The **PTFE tubes come pre-cut** — no cutting needed. You'll have **two of each length**:

| Length | Size | Quantity |
| --- | --- | --- |
| Short | 10 mm | 2 |
| Medium | 40 mm | 2 |
| Long | 70 mm | 2 |

<!-- 📷 media/build-guide/16-long-tubes.png — 2 long tubes placed, top plastic attached with 2 screws -->
1. **Long tubes.** Place the **two long tubes**, then attach the top plastic using **two M3 thread-forming screws**.

<!-- 📷 media/build-guide/17-pulley-end.png — pulley end: short tubes, V-groove pulley with M3×15mm button head, square nut, M3 thread-forming -->
2. **Pulley end.** Fit the **short tubes**, then the **V-groove pulley** held by an **M3 × 15 mm button-head screw**, secured with an **M3 square nut** and an **M3 thread-forming screw**.

<!-- 📷 media/build-guide/18-carriages-medium.png — 1 medium tube per carriage, top plastic over tubes, 4 side screws -->
3. **Carriages — build two.** For **each** carriage, place **one medium tube** in, set the top plastic over the tubes, and drive **four M3 thread-forming screws into the sides** (four per carriage, **eight total**). Then add the **top screws that tell the two carriages apart — one on the first carriage, two on the second** (**three total**); these become the rope clamp/tension screws later (see [Rope routing and tensioning](#rope-routing-and-tensioning)).

> **Curtain-side screw count:** 2 (long tubes) + 1 (pulley end) + 8 (carriage sides) + 3 (carriage tops) = **14 M3 × 10 thread-forming screws**. With the **8** in the motor body, a full build uses **22** — matching the [Bill of Materials](https://github.com/Valar-Systems/Ropener/blob/main/docs/BOM-V2.0.md).

---

## Attaching to your curtains

<!-- 📷 media/build-guide/20a-elbow-ziptie.png — motor-side rope elbow zip-tied to rod wall mount; 📷 20b-pulley-ziptie.png — pulley zip-tied to far wall mount -->
1. **Mount the rope elbow (motor side).** Zip-tie the hole of the elbow to your curtain-rod wall mount.
2. **Mount the pulley (far side).** Zip-tie the pulley to the wall mount at the opposite end.
3. **Pick your curtain type** below and follow the matching steps.

### Grommet
- No extra parts — the whole carriage simply pushes against the grommets.
- **Glide tape is usually required**, because grommets create too much friction. Glide tape is a thick plastic tape applied to the top of the rod that reduces friction.
- The carriage hangs freely **behind the first loop** of the curtain panel.

<!-- 📷 media/build-guide/24-grommet.png — glide tape on rod + carriage behind first loop -->

### Back-tab
- Use the **toothed clamps**: clamp the back tab between the clamp and the carriage, then secure with **M3 thread-forming screws** on the back.

<!-- 📷 media/build-guide/25-backtab.png — toothed clamp clamping the back tab, screws on the back -->

### Ring
- Use **zip ties** through the two slots in the carriage.
- Keep the **excess tail and the zip-tie head on the back side** of the carriage so they don't interfere with the rings.

<!-- 📷 media/build-guide/26-ring.png — zip tie through carriage slots, head on back side -->

### Top-tab
- Not formally tested, but it's expected to work well using the **same approach as back-tab**.

---

## Rope routing and tensioning

> If you have **back-tab or ring** curtains, attach the carriages to the curtains **first**.

<!-- 📷 media/build-guide/27-rope-routing.png — rope path: through motor-side elbow, both ends exit the 2-screw carriage (Exit 1 / Exit 2) -->
1. **Route the rope** through the **motor-side elbow first**.
2. Route both rope ends so they **exit from the carriage that has two screws on top** (Exit 1 and Exit 2).
3. **Leave the carriage clamp screw loose for now** — only screw it down at the very end, once you've found the correct rope position.

<!-- 📷 media/build-guide/28-motor-below-elbow.png — motor mounted directly below the elbow so the rope is straight -->
4. **Mount the motor directly below the elbow** so the rope runs straight down.

<!-- 📷 media/build-guide/29-rope-to-pulley.png — loosen clamp screw, push rope over pulley, re-tighten clamp; carriage tension screw -->
5. **Attach the rope to the motor pulley.** Loosen the clamp screw, push the rope over the pulley, then re-secure the clamp screw.
   - ⚠️ **Don't overtighten** the clamp screw — the motor won't be able to turn it. But if it's too loose, the pulley won't grip the rope.
6. **Tension the rope.** Loosen the screw on the carriage, pull the excess rope out until the rope is taut, then tighten it down.

> 🔧 **Moving it by hand:** to turn the rope manually, only **PULL UP** from the motor pulley — **never pull down** on the rope.

---

## Next steps

1. **Install it** on your curtains — [🪟 Installation Guide](Installation-Guide).
2. **Flash & configure the firmware** — [⚙️ Firmware Guide](Firmware-Guide) · [ESPHome Guide](ESPHome-guide).
3. **Start using it** — [📖 User Guide](User-Guide).

---

> 💬 Stuck on a step? Email **daniel@valarsystems.com** or [open an issue](https://github.com/Valar-Systems/Ropener/issues) with a photo and we'll help.

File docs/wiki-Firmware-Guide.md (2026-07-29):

# ⚙️ Firmware Guide

*For advanced users — what the Ropener firmware actually is, how it works, and how to flash or update it from the YAML file.*

Ropener runs on **[ESPHome](https://esphome.io)**, an open-source firmware framework. The entire behaviour of the device — the web page, the motor logic, the buttons, the schedule — is described in a single human-readable YAML file and compiled into a binary that runs on the on-board ESP32. There is no closed-source blob and no cloud account: if you can read the YAML, you can see (and change) everything the device does.

> 💡 If you only want to **use** the device, you don't need any of this — see the [User Guide](User-Guide). This page is for people who want to recompile, update, or modify the firmware themselves.

---

## Contents

1. [What is ESPHome?](#1-what-is-esphome)
2. [How the Ropener firmware is built](#2-how-the-ropener-firmware-is-built)
3. [Which YAML file is mine?](#3-which-yaml-file-is-mine)
4. [What you may and may not change](#4-what-you-may-and-may-not-change)
5. [Tools for flashing](#5-tools-for-flashing)
6. [Updating the firmware from the YAML](#6-updating-the-firmware-from-the-yaml)
7. [First flash vs. over-the-air (OTA) updates](#7-first-flash-vs-over-the-air-ota-updates)
8. [secrets.yaml and API encryption (optional)](#8-secretsyaml-and-api-encryption-optional)
9. [External components](#9-external-components)
10. [After flashing](#10-after-flashing)
11. [Troubleshooting](#11-troubleshooting)

---

## 1. What is ESPHome?

ESPHome turns a **YAML description** of a device into real firmware. You write *what* the device should expose — a cover, some buttons, a few numbers, a web server — and ESPHome generates the C++, compiles it for the ESP32, and flashes it.

A few ideas worth knowing before you touch the file:

- **The YAML is the source of truth.** Nothing is configured by clicking around after the fact at the firmware level — every pin, entity, and behaviour comes from the file. Re-flashing the same YAML reproduces the same firmware exactly.
- **Entities, not screens.** ESPHome thinks in *entities*: a `cover`, a `switch`, a `number`, a `sensor`, etc. The built-in web page and Home Assistant both render whatever entities the YAML declares — that's why the web UI and Home Assistant always show the same controls.
- **It runs locally.** The device serves its own control page (`web_server:`) and talks to Home Assistant directly over the local network (`api:`). No internet round-trip is needed to move the curtain; the only thing that needs the network is clock sync for the schedule.
- **Two kinds of settings.** *Compile-time* values (like the gear ratio) are baked into the binary and need a re-flash to change. *Runtime* values (speed, travel distance, timezone…) are exposed as entities you edit in the browser, and they persist in flash across reboots and updates. See [Section 4](#4-what-you-may-and-may-not-change).

If you've never used ESPHome, the official [Getting Started guide](https://esphome.io/guides/getting_started_command_line.html) is a good companion to this page.

---

## 2. How the Ropener firmware is built

At a high level, the curtain hardware is an **ESP32** microcontroller driving a **TMC2209** silent stepper driver, which turns a **NEMA-17 motor** and an **MK8 gear** that pulls the poly rope. The YAML wires all of that together. The main building blocks in the file:

| YAML section | What it does |
| --- | --- |
| `esphome:` / `esp32:` | Device name, firmware version, board variant, and the `on_boot:` sequence that restores saved settings into the motor driver. |
| `external_components:` | Pulls in the TMC2209 stepper component (see [Section 9](#9-external-components)). |
| `wifi:` / `captive_portal:` / `improv_serial:` | Wi-Fi provisioning. The firmware ships with **no** saved network, so a fresh unit broadcasts a `ropener-XXXXXX` setup hotspot. |
| `web_server:` | The built-in control page at `http://ropener-XXXXXX.local`, grouped into Control / Setup / Schedule / Motion / StallGuard / Diagnostics. |
| `api:` | The native ESPHome API used by Home Assistant (optional, unencrypted by default). |
| `ota:` | Over-the-air update support, so later updates don't need a USB cable. |
| `stepper:` + `cover:` | The motion engine. Position is tracked in motor *steps* and reported to the UI as a 0–1 (closed→open) ratio. |
| `binary_sensor:` (buttons) | The three physical buttons (close/home, open, Wi-Fi reset). |
| `number:` / `switch:` / `text:` / `datetime:` | The runtime-tunable settings — travel distance, speed, motor direction, schedule times, timezone, latitude/longitude, StallGuard thresholds. |
| `time:` + `sun:` + `interval:` | The daily schedule, including the optional sunrise/sunset mode. |

You don't need to understand every line to update the firmware — but it's all commented in the file itself if you want to dig in.

---

## 3. Which YAML file is mine?

The YAML source for each board lives in its own sub-folder under [`firmware/`](https://github.com/Valar-Systems/Ropener/tree/main/firmware); the matching **pre-built binaries are attached to each [release](https://github.com/Valar-Systems/Ropener/releases/latest)**. Every release provides two binaries per board — a `*.factory.bin` (full image for the first USB flash) and a `*.ota.bin` (the over-the-air update image you upload from the device's web page). So you can build from source, flash the factory image with no tools, or update an already-running device straight from its browser (see [Section 6](#6-updating-the-firmware-from-the-yaml)). The v2.6.1 files:

| Board | Microcontroller | YAML source | Factory image — first USB flash | OTA image — Wi-Fi update |
| --- | --- | --- | --- | --- |
| **VAL3100** | ESP32-**C6** | [`Ropener-VAL3100-2.6.1.yml`](https://github.com/Valar-Systems/Ropener/blob/main/firmware/VAL3100/Ropener-VAL3100-2.6.1.yml) | [`Ropener-VAL3100-2.6.1.factory.bin`](https://github.com/Valar-Systems/Ropener/releases/download/v2.6.1/Ropener-VAL3100-2.6.1.factory.bin) | [`Ropener-VAL3100-2.6.1.ota.bin`](https://github.com/Valar-Systems/Ropener/releases/download/v2.6.1/Ropener-VAL3100-2.6.1.ota.bin) |
| **VAL3000** | ESP32-**C3** | [`Ropener-VAL3000-2.6.1.yml`](https://github.com/Valar-Systems/Ropener/blob/main/firmware/VAL3000/Ropener-VAL3000-2.6.1.yml) | [`Ropener-VAL3000-2.6.1.factory.bin`](https://github.com/Valar-Systems/Ropener/releases/download/v2.6.1/Ropener-VAL3000-2.6.1.factory.bin) | [`Ropener-VAL3000-2.6.1.ota.bin`](https://github.com/Valar-Systems/Ropener/releases/download/v2.6.1/Ropener-VAL3000-2.6.1.ota.bin) |

> ⚠️ **The board variants are not interchangeable.** The C3 and C6 use different GPIO pin assignments, so flashing the wrong board's YAML or binary will leave the buttons and motor mis-wired. If you're not sure which board you have, check the silk-screen label on the PCB.

> 🏠 **Want Alexa / Apple Home / Google Home?** You don't need a separate firmware for that — pair the standard build with [Matterbridge](https://github.com/Luligu/matterbridge) to bridge the curtain into those ecosystems. See the [README](https://github.com/Valar-Systems/Ropener#readme).

---

## 4. What you may and may not change

*This section only matters if you **build from the YAML** (Path B). If you flash the ready-made binary (Path A), there's nothing to edit — skip to [Section 6](#6-updating-the-firmware-from-the-yaml).*

When building from source, the one thing most people change is the device name in the `esphome:` block, to give the unit a friendly label:

```yaml
esphome:
  name: ropener-bedroom-1                 # optional — a friendly name
  friendly_name: "Ropener Bedroom 1"      # optional
```

You don't have to rename it: `name_add_mac_suffix: true` already makes every unit unique as `ropener-XXXXXX`. Change it only if you want something more memorable.

Everything else should be left alone unless you know exactly what you're doing. In particular:

- **Don't touch the `substitutions:` block** (`gear_distance_cm`, `steps_per_revolution`). These are mechanical constants tied to the actual gear and microstepping; changing them breaks the distance calibration.
- **Don't touch the pin numbers** in `uart:`, `stepper:`, and the button `binary_sensor:` entries — they match the PCB.
- **You don't need to edit travel distance, speed, schedule, timezone, etc. in the YAML.** Those are runtime settings: flash once, then set them from the web page (they persist across reboots and future updates). See the [ESPHome Guide](ESPHome-guide) and [User Guide](User-Guide).

> 🛑 **StallGuard warning.** Do **not** enable or tune StallGuard-based auto-homing unless you have set it up correctly — it's finicky and needs exact `SGTHRS`/`TCOOLTHRS` values. It is not required for the device to work; home the curtain manually instead (see the [User Guide](User-Guide#5-homing-calibrating-the-closed-position)).

---

## 5. Tools for flashing

Only ESPHome itself can **compile** the YAML into firmware — a web page can't. Pick whichever tool fits how you work:

| Tool | What it does | Notes |
| --- | --- | --- |
| **ESPHome CLI** (`pip install esphome`) | Compiles the YAML **and** flashes it | `esphome run file.yml` — over USB or OTA. Needs [Python](https://www.python.org/). |
| **ESPHome Dashboard** | Compiles **and** flashes, via a local web UI | Standalone (`esphome dashboard`) or the Home Assistant **ESPHome** add-on. USB and OTA. |
| **ESPHome Web** ([web.esphome.io](https://web.esphome.io)) | **Flashes a pre-built `.bin`** — does *not* compile | Runs in Chrome/Edge, no install, USB only (no OTA). Flash the ready-made `.factory.bin` we ship ([Section 3](#3-which-yaml-file-is-mine)) — or one you compiled yourself. |

In short: the CLI and the Dashboard turn the YAML into firmware; ESPHome Web just writes a finished binary — and since we ship one in each board's folder, a standard install needs no compiling at all.

---

## 6. Updating the firmware from the YAML

How you get firmware onto the device depends on its state — pick the matching method:

- **Already running Ropener?** Update it straight from its web page — no tools, no USB (see just below).
- **New / blank board?** Flash the factory image over USB — **Path A**.
- **Want to customize the YAML or script updates?** Build from source — **Path B**.

> 📦 **Two binary types.** First-time USB flashing uses the **factory image** (`*.factory.bin`). Over-the-air updates use the **OTA image** (`*.ota.bin`, ESPHome's "Modern format"). Each board folder ships both ([Section 3](#3-which-yaml-file-is-mine)) — don't upload a factory image to an OTA updater.

### Update in the device's web page (already running ESPHome — no tools)

If the device already runs Ropener firmware and is on your network, this is the simplest way to update it — no USB cable and nothing to install:

1. Open the device's control page (`http://ropener-XXXXXX.local`) in any browser on the same network.
2. Scroll to the **OTA Update** card.
3. Click **Choose File** and select the new **OTA image** — your board's `*.ota.bin` (e.g. `Ropener-VAL3100-2.6.1.ota.bin`), **not** the `*.factory.bin`.
4. Click **Update**. The device flashes the new build and reboots; your Wi-Fi and saved settings are kept.

> 💡 You can push the same OTA from the ESPHome CLI/Dashboard instead (Path B, over the network) — handy for scripting or bulk updates.

### Path A — Flash the ready-made binary with ESPHome Web (no install)

Each board folder ships a pre-compiled `*.factory.bin`, so you can flash without installing ESPHome or compiling anything.

1. Download your board's `*.factory.bin` from [Section 3](#3-which-yaml-file-is-mine) (e.g. `Ropener-VAL3100-2.6.1.factory.bin`).
2. Plug the device into your computer over USB.
3. Go to **[web.esphome.io](https://web.esphome.io)** in Chrome or Edge and click **Connect**; pick the device's serial port.
4. Click **Install**, choose the `.factory.bin` you downloaded, and let it flash.

> 💡 **Nothing to configure first.** The stock build names itself `ropener` plus a per-device MAC suffix, so every unit comes up unique as `ropener-XXXXXX`. Want a custom friendly name, API encryption, or different motion defaults? Build from source instead (Path B).

### Path B — Build from the YAML with the ESPHome CLI or Dashboard

Use this to customize the firmware, or to update over Wi-Fi (OTA) after the first flash.

1. Install ESPHome: `pip install esphome` (or use the Home Assistant **ESPHome** add-on / `esphome dashboard`).
2. Save the correct YAML for your board ([Section 3](#3-which-yaml-file-is-mine)) locally and edit the device name ([Section 4](#4-what-you-may-and-may-not-change)).
3. Compile and flash in one step:
   ```bash
   esphome run Ropener-VAL3100-2.6.1.yml
   ```
   The first time, choose the **USB/serial** port. Once the device is on your network the same command offers an **OTA (Over-The-Air)** option — no cable needed.
4. Watch the boot log to confirm it came up cleanly:
   ```bash
   esphome logs Ropener-VAL3100-2.6.1.yml
   ```

> 🔧 **Flashing a customized build through the browser?** Run `esphome compile Ropener-VAL3100-2.6.1.yml` to produce your own `*.factory.bin` (ESPHome writes it under `.esphome/build/<device-name>/…`), then flash it with Path A from step 2.

> 📝 **Wi-Fi survives updates.** Re-flashing does **not** erase your saved Wi-Fi network or your runtime settings — they live in a separate area of flash. You only re-provision Wi-Fi after a deliberate Wi-Fi reset (hold Button 3, see the [User Guide](User-Guide#9-resetting-wi-fi)).

---

## 7. First flash vs. over-the-air (OTA) updates

- **First flash must be over USB.** A brand-new or blank chip has no firmware to receive an OTA, so the very first install needs a cable.
- **Every update after that can be OTA** — either upload the `*.ota.bin` in the device's **OTA Update** web card ([Section 6](#6-updating-the-firmware-from-the-yaml)), or push it from the ESPHome CLI/Dashboard (pick the device's network address instead of a serial port). Both use the `*.ota.bin` image, not the factory image.
- **OTA requires the device to be on the same network** and reachable at `ropener-XXXXXX.local` (or its IP address).

---

## 8. secrets.yaml and API encryption (optional)

The firmware compiles **without a `secrets.yaml`** out of the box — there are no hardcoded Wi-Fi credentials or keys to supply.

The only reason to create one is to enable **encryption on the Home Assistant API**. By default the native API is unencrypted, and Home Assistant shows a "Communication not encrypted" warning when you first add the device. The device still works normally. To silence the warning:

1. Generate a 32-byte base64 key:
   ```bash
   python3 -c "import secrets,base64; print(base64.b64encode(secrets.token_bytes(32)).decode())"
   ```
2. Put it in a `secrets.yaml` next to the firmware:
   ```yaml
   api_key: "your-generated-key-here"
   ```
3. Uncomment the encryption block in the `api:` section of the YAML:
   ```yaml
   api:
     encryption:
       key: !secret api_key
   ```
4. Re-flash, then add the key in Home Assistant when prompted.

---

## 9. External components

The TMC2209 stepper driver isn't part of core ESPHome, so the firmware pulls it from a community repository at compile time:

```yaml
external_components:
  - source: github://slimcdk/esphome-custom-components
    components: [tmc2209_hub, tmc2209, stepper]
```

ESPHome downloads and caches this automatically on the first build — you don't need to install anything by hand. It does mean the **first compile needs an internet connection**; later builds use the cached copy.

---

## 10. After flashing

A successful flash gets you a running device, but it still needs to be set up:

1. **Provision Wi-Fi** — connect to the `ropener-XXXXXX` hotspot (or use Improv over USB). See [User Guide §2](User-Guide#2-first-time-setup-connect-to-wi-fi).
2. **Configure the device** — set travel distance (Centimeters), motor direction, and home the curtain. See the [ESPHome Guide](ESPHome-guide).
3. **Use it** — schedule, positions, Home Assistant, etc. See the [User Guide](User-Guide).

---

## 11. Troubleshooting

| Symptom | What to try |
| --- | --- |
| Compile fails on first build | Check your internet connection — ESPHome needs to download the external TMC2209 component once. |
| "Wrong" buttons or motor won't move | You may have flashed the wrong board's YAML. Confirm VAL3000 (C3) vs. VAL3100 (C6) and re-flash the matching file ([Section 3](#3-which-yaml-file-is-mine)). |
| Can't flash over USB | Try a different (data-capable) USB cable, and a Chromium-based browser for ESPHome Web. Some boards need to be put into bootloader mode. |
| OTA option doesn't appear | The device must already be running this firmware and reachable on the network. Do the first flash over USB. |
| OTA update rejected / "invalid image" | You picked the wrong file — the **OTA Update** card needs the `*.ota.bin` (Modern format), not the `*.factory.bin` (that's only for the initial USB flash). |
| Home Assistant says "not encrypted" | Expected — the device works anyway. Enable API encryption if you want to remove it ([Section 8](#8-secretsyaml-and-api-encryption-optional)). |
| Lost Wi-Fi / settings after update | Re-flashing does not erase them; if Wi-Fi is gone, the device was likely Wi-Fi-reset. Re-provision via the hotspot ([User Guide §2](User-Guide#2-first-time-setup-connect-to-wi-fi)). |

---

*Still stuck? [Open an issue](https://github.com/Valar-Systems/Ropener/issues) — and see the [ESPHome Guide](ESPHome-guide) and [User Guide](User-Guide) for day-to-day configuration.*

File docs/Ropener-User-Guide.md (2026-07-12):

# Ropener Curtain Controller — User Guide

*Firmware 2.6.4*

---

Ropener is a Wi-Fi connected curtain/cover controller. It pulls a poly rope with a small stepper motor to open and close your curtains. You can control it from any web browser on your network — no Home Assistant or cloud account required — or pair it with Home Assistant if you use one. It supports a daily open/close schedule (by fixed clock times or sunrise/sunset), automatic position calibration, and several tuning options.

---

## Contents

1. [At a Glance](#1-at-a-glance)
2. [First-Time Setup: Connect to Wi-Fi](#2-first-time-setup-connect-to-wi-fi)
3. [Open the Web Control Panel](#3-open-the-web-control-panel)
4. [Everyday Use](#4-everyday-use)
5. [Homing (Calibrating the Closed Position)](#5-homing-calibrating-the-closed-position)
6. [Set Up the Daily Schedule](#6-set-up-the-daily-schedule)
7. [Setting Your Timezone](#7-setting-your-timezone)
8. [Timezone POSIX Strings](#8-timezone-posix-strings)
9. [Resetting Wi-Fi](#9-resetting-wi-fi)
10. [Adjusting How It Moves (Advanced)](#10-adjusting-how-it-moves-advanced)
11. [Home Assistant (Optional)](#11-home-assistant-optional)
12. [Troubleshooting](#12-troubleshooting)
13. [Quick Reference](#13-quick-reference)

---

## 1. At a Glance

- **Control from a browser:** open the device's web page on your phone or computer.
- **Three ways to operate:** the web page, the physical buttons on the device, or Home Assistant.
- **Open / close / partial:** drive the curtain fully open, fully closed, or to any position in between.
- **Daily schedule:** open and close automatically every day — at fixed clock times, or following sunrise and sunset.
- **Self-calibrating:** the device finds the fully-closed position by itself (“homing”).

---

## 2. First-Time Setup: Connect to Wi-Fi

The device ships without any saved Wi-Fi network, so the first thing to do is tell it which network to join. There are two ways to do this.

### Option A — The setup hotspot (recommended)

- Power on the device and wait about a minute.
- On your phone or laptop, open the Wi-Fi network list. You will see a network named **“ropener-XXXXXX”**, where XXXXXX is a unique code for your device.
- Write down or take a photo of this full name now — you will need the same “ropener-XXXXXX” to open the device in your browser later (see Section 3). The hotspot disappears once setup is done, so note it before continuing.
- Connect to it. A setup page should open automatically (this is the “captive portal”). If it does not, open a browser and go to `http://192.168.4.1`.
- Choose your home Wi-Fi network from the list, enter its password, and save.
- The device will reboot and join your network. The setup hotspot disappears once it connects successfully.

> **Remember:** the “ropener-XXXXXX” code is also your device's web address — you'll type `http://ropener-XXXXXX.local` into a browser to control it. Keep the code handy.

### Option B — Over USB (Improv)

If the device is plugged into a computer over USB, you can provision it from a web tool that supports “Improv” (for example, [web.esphome.io](https://web.esphome.io)). Open the tool, connect to the device's serial port, and enter your Wi-Fi details when prompted.

> **Note:** Your Wi-Fi details are stored on the device and kept across reboots and firmware updates. You only need to do this once (unless you reset Wi-Fi — see Section 9).

---

## 3. Open the Web Control Panel

Once the device is on your network, open a web browser on the same network and go to:

```
http://ropener-XXXXXX.local
```

Replace XXXXXX with your device's code (the same code shown in the setup hotspot name). The page lists every control and reading described in this guide. Bookmark it for easy access.

> **Tip:** If the `.local` address does not load, your network may not support it. In that case, find the device's IP address in your router and use `http://<that-ip>` instead.

---

## 4. Everyday Use

### From the web page or Home Assistant

- **Open:** raises the cover to the fully-open position.
- **Close:** lowers the cover to the fully-closed position.
- **Set a position:** drag the cover slider to any point from 0% (closed) to 100% (open).
- **Stop:** halts movement immediately and leaves the cover where it is.

### Using the physical buttons

The device has three buttons. While the cover is moving, a press of Button 1 or Button 2 stops it immediately. You can also press and hold a button to move the cover only while you hold it — it stops the moment you let go, and stops on its own at the fully open or closed end. This keeps it safe around children and the elderly: the cover never keeps moving on its own.

| Button | Action | What it does |
| --- | --- | --- |
| Button 1 | Tap | Closes the cover (or stops it if moving). |
| Button 1 | Press and hold | Closes only while held; stops on release and at the closed end. |
| Button 1 | Seven quick taps | Starts homing / calibration (see Section 5). |
| Button 2 | Tap | Opens the cover (or stops it if moving). |
| Button 2 | Press and hold | Opens only while held; stops on release and at the open end. |
| Button 1 + Button 2 | Hold both 3 sec | Sets the current position as home / 0% (see Section 5). |
| Button 3 | Long press (3–10 sec) | Clears saved Wi-Fi and reboots into setup (see Section 9). |

---

## 5. Homing (Calibrating the Closed Position)

> ⚠️ **Important — you must stop homing manually (automatic stop is disabled)**
>
> The sensor that normally detects the closed end (called “StallGuard”) is not working in this version of the firmware. During homing the motor will **NOT** stop by itself. You must watch the curtain and press Stop the moment it reaches the fully-closed position. If you do not stop it, the motor will keep running and strain against the stop. Always stay with the device while homing.

“Homing” teaches the device where the fully-closed position is. The motor drives the curtain toward the closed end; when it arrives, you stop it, and the device marks that spot as 0% (closed). Everything else — the open position, percentages, and the schedule — is measured from there.

Run homing when:

- You first install the device.
- The reported position no longer matches reality (for example after the rope slipped or was pulled by hand).

### How to home (stop it yourself)

1. Start homing: tap Button 1 **seven times quickly**, or click the “Start-Stop Homing” button on the web page.
2. Watch the curtain drive toward the closed end.
3. The instant it reaches the fully-closed position, press Stop — press **either button** once, or click “Start-Stop Homing” again. This marks that spot as 0% (closed) and ends homing.

The “State” reading on the web page shows **HOMING** while homing is running and returns to **IDLE** once you press Stop.

**Gentler alternative (no straining against the stop):** use press-and-hold to inch the curtain to the fully-closed position, then hold both buttons together for 3 seconds. The device marks the current spot as home (0%) without driving into the end.

---

## 6. Set Up the Daily Schedule

The device can open and close the curtain automatically every day. There are **two scheduling modes** — pick the one you prefer:

- **Fixed times** — open and close at clock times you choose (e.g. 07:00 and 21:00).
- **Sunrise / sunset** — open at sunrise and close at sunset, so the curtain follows the daylight as it shifts through the seasons.

“Schedule Enabled” is the master on/off for whichever mode is active. The “Sun Schedule” switch chooses between the two: OFF uses the fixed times, ON uses sunrise/sunset. Both modes run on local time, so set your Timezone first (Section 7).

### Fixed times (default)

| Control | What to set |
| --- | --- |
| Open Time | The time of day to open the cover (e.g. 07:00). |
| Close Time | The time of day to close the cover (e.g. 21:00). |
| Sun Schedule | Leave this **OFF** to use fixed times. |
| Schedule Enabled | Turn this ON to run the schedule, OFF to pause it. |
| Timezone | Your local timezone, so the times mean what you expect (see Section 7). |

**Steps:**

1. Set your Timezone first (Section 7) — the open/close times are in local time.
2. Set Open Time and Close Time.
3. Make sure Sun Schedule is OFF.
4. Turn Schedule Enabled ON.

### Sunrise / sunset (Sun Schedule)

Turn “Sun Schedule” ON to follow the sun instead of the clock. The curtain opens at sunrise and closes at sunset for your location, recalculated every day so it tracks the changing seasons automatically — no need to adjust times by hand.

For this to be accurate, the device needs to know where it is. Enter your **Latitude** and **Longitude** in decimal degrees (north and east are positive; south and west are negative). You can copy these from any maps app — for example, New York is about Latitude `40.71`, Longitude `-74.01`.

| Control | What to set |
| --- | --- |
| Sun Schedule | Turn this **ON** to use sunrise/sunset. |
| Latitude | Your location's latitude in decimal degrees (e.g. 40.71). |
| Longitude | Your location's longitude in decimal degrees (e.g. -74.01). |
| Sun Open Offset | Minutes to shift the morning open relative to sunrise (see below). |
| Sun Close Offset | Minutes to shift the evening close relative to sunset (see below). |
| Schedule Enabled | Turn this ON to run the schedule. |
| Timezone | Your local timezone (see Section 7). |

**Offsets** let you open or close a little before or after the sun, in minutes:

- A **positive** offset is *after* the event; a **negative** offset is *before* it.
- To open 30 minutes **after** sunrise, set Sun Open Offset to `30`.
- To close 30 minutes **before** sunset, set Sun Close Offset to `-30`.
- Leave both at `0` to open exactly at sunrise and close exactly at sunset.

**Steps:**

1. Set your Timezone (Section 7).
2. Enter your Latitude and Longitude.
3. Optionally set the open/close offsets.
4. Turn Sun Schedule ON.
5. Turn Schedule Enabled ON.

> **Notes:** Both schedules need an internet connection to keep accurate time. Scheduled moves are skipped while the device is homing, and every schedule setting is remembered across reboots. With Sun Schedule ON the fixed Open Time / Close Time are ignored. If you leave Latitude and Longitude at 0, sunrise/sunset will not match your location — set them before relying on the sun schedule.

---

## 7. Setting Your Timezone

The device keeps time using the internet, which provides time in UTC. To make the schedule fire at the correct local time, enter your timezone in the “Timezone” box using a POSIX timezone string. Copy the value for your region from the table in Section 8 and paste it into the Timezone box, then save.

**Example:** for U.S. Eastern time with daylight saving, enter `EST5EDT,M3.2.0,M11.1.0`.

> **Important about the number sign:** In a POSIX timezone string the number is the hours WEST of UTC, so it looks “backwards” compared to the usual UTC offset. U.S. Eastern (UTC−5) is written as 5, Pacific (UTC−8) as 8, and so on. The table in Section 8 already has this right — just copy it exactly, including capitalization and punctuation.

The trailing parts (for example “,M3.2.0,M11.1.0”) are the daylight-saving rules. The U.S. switches on the 2nd Sunday of March and the 1st Sunday of November; the European Union switches on the last Sunday of March and the last Sunday of October. The tables in Section 8 already encode the correct rule for each region — just copy the value exactly. If your area does not observe daylight saving time, use the “without DST” value, which has no trailing rules.

---

## 8. Timezone POSIX Strings

Find your region below and copy the matching string into the Timezone box. Use the “With DST” column if your area changes its clocks twice a year; use “Without DST (standard all year)” if it does not.

### United States

| Zone | Where it's used | With DST | Without DST (standard all year) |
| --- | --- | --- | --- |
| Eastern | New York, Florida, Ohio, most of the East Coast | `EST5EDT,M3.2.0,M11.1.0` | `EST5` |
| Central | Texas, Illinois, Tennessee (western), most of the Midwest | `CST6CDT,M3.2.0,M11.1.0` | `CST6` |
| Mountain | Colorado, Utah, Montana, New Mexico | `MST7MDT,M3.2.0,M11.1.0` | `MST7` |
| Mountain (Arizona) | Most of Arizona — no daylight saving | *(not used)* | `MST7` |
| Pacific | California, Washington, Oregon, Nevada | `PST8PDT,M3.2.0,M11.1.0` | `PST8` |
| Alaska | Most of Alaska | `AKST9AKDT,M3.2.0,M11.1.0` | `AKST9` |
| Hawaii–Aleutian (Aleutian Is.) | Western Aleutian Islands, AK — observes DST | `HST10HDT,M3.2.0,M11.1.0` | `HST10` |
| Hawaii | State of Hawaii — no daylight saving | *(not used)* | `HST10` |
| Atlantic | Puerto Rico, U.S. Virgin Islands — no daylight saving | *(not used)* | `AST4` |
| Samoa | American Samoa — no daylight saving | *(not used)* | `SST11` |
| Chamorro | Guam, Northern Mariana Islands — no daylight saving | *(not used)* | `ChST-10` |
| Wake Island | Wake Island — no daylight saving | *(not used)* | `<+12>-12` |

*Zones marked “(not used)” under With DST do not observe daylight saving time, so only the standard-time string applies. Daylight-saving rules shown reflect current U.S. law (spring forward 2nd Sunday of March, fall back 1st Sunday of November).*

### Europe

Most of Europe observes EU daylight saving (forward on the last Sunday of March, back on the last Sunday of October). Countries that do not change their clocks are listed with a single standard-time value.

| Zone | Where it's used | With DST | Without DST (standard all year) |
| --- | --- | --- | --- |
| Western European | Portugal (mainland), Canary Islands | `WET0WEST,M3.5.0/1,M10.5.0` | `WET0` |
| UK / Ireland | United Kingdom, Ireland | `GMT0BST,M3.5.0/1,M10.5.0` | `GMT0` |
| Central European | France, Germany, Spain, Italy, Netherlands, Belgium, Poland, Sweden, Norway, Denmark, Switzerland, Austria, Czechia — most of central Europe | `CET-1CEST,M3.5.0,M10.5.0/3` | `CET-1` |
| Eastern European | Greece, Finland, Romania, Bulgaria, Estonia, Latvia, Lithuania, Ukraine | `EET-2EEST,M3.5.0/3,M10.5.0/4` | `EET-2` |
| Azores | Azores (Portugal) | `<-01>1<+00>,M3.5.0/0,M10.5.0/1` | `<-01>1` |
| Iceland | Iceland — no daylight saving | *(not used)* | `GMT0` |
| Kaliningrad | Kaliningrad, Russia — no daylight saving | *(not used)* | `EET-2` |
| Moscow | Moscow / western Russia — no daylight saving | *(not used)* | `MSK-3` |
| Belarus | Minsk, Belarus — no daylight saving | *(not used)* | `<+03>-3` |
| Turkey | Türkiye — no daylight saving | *(not used)* | `<+03>-3` |

*Zones marked “(not used)” under With DST do not change their clocks. POSIX values are taken directly from the IANA time zone database.*

---

## 9. Resetting Wi-Fi

If you move the device to a new network, or want to hand it to someone else, you can erase the saved Wi-Fi details:

- Press and hold Button 3 for 3 to 10 seconds.
- The device erases its saved network and reboots.
- After rebooting it broadcasts the “ropener-XXXXXX” setup hotspot again — follow Section 2 to connect it to a network.

> **Note:** This only clears Wi-Fi credentials. Your schedule, timezone, and tuning settings are kept.

---

## 10. Adjusting How It Moves (Advanced)

These settings are optional. The defaults work for a typical installation; change them only if needed. All values are remembered across reboots.

| Setting | What it controls | Notes |
| --- | --- | --- |
| Centimeters | Total travel distance of the curtain, in cm. | Set this to your curtain's open-to-closed travel. Default 30 cm. |
| Speed | How fast the motor runs (steps/second). | Higher is faster but louder. Effective max is 2000. |
| Acceleration | How quickly the motor speeds up / slows down. | Higher is snappier; too high can skip or be noisy. |
| Motor Direction | Which way the motor winds the rope (**Normal** / **Reversed ↺**). | Set to **Reversed** if Open and Close are backwards for your install. Your choice is saved and survives a power loss. |
| IRUN value | Motor running current / torque (1–31). | Raise for more pulling force; lower if the driver runs hot. Default 25. |
| SGTHRS value | Sensitivity of the stall detection used for homing (0–255). | See tuning note below. |
| TCOOLTHRS value | Speed threshold above which stall detection is active. | See tuning note below. |

### Tuning stall-based homing (optional)

> **Note:** automatic stall detection is not working in the current firmware, so the SGTHRS / TCOOLTHRS settings have no effect yet — home manually by pressing Stop at the closed position (see Section 5). The guidance below applies once automatic detection is restored.

Homing is meant to detect when the motor meets resistance at the closed end. Two readings on the web page help you tune it:

- **SG_RESULT Sensor:** a live load reading that drops as the motor works harder.
- **TSTEP Sensor:** a measure of motor speed (smaller means faster).

To tune: run the cover under normal load while watching SG_RESULT, note the value it settles at, then set SGTHRS to roughly half of that. If homing stops too early (false stalls), lower SGTHRS; if it does not detect the stop, raise it. Leave these at their defaults unless homing is unreliable.

---

## 11. Home Assistant (Optional)

If you use Home Assistant, the device is discovered automatically over the local network and appears as a cover plus all the controls and readings in this guide. You do not need Home Assistant to use any feature — the web page offers the same controls.

When first added, Home Assistant may warn that communication is not encrypted. The device still works normally. To remove the warning, an encryption key can be enabled in the firmware configuration (a setup step for the installer).

---

## 12. Troubleshooting

| Symptom | What to try |
| --- | --- |
| Can't find the web page | Make sure your phone/PC is on the same Wi-Fi as the device. Try the device's IP address instead of the `.local` name. Confirm it joined Wi-Fi (the setup hotspot should be gone). |
| No setup hotspot appears | Wait a full minute after power-on. If it already joined a network, hold Button 3 for 3–10 seconds to reset Wi-Fi and try again. |
| Open/Close are reversed | Set the “Motor Direction” setting to **Reversed**. |
| Position is wrong / drifted | Run homing (Section 5) to recalibrate. |
| Schedule fires at the wrong time | Check the Timezone value (Section 7/8) and that the device has internet for time sync. |
| Schedule doesn't run | Confirm “Schedule Enabled” is ON and that Open/Close times are set. |
| Sun schedule opens/closes at the wrong time | Set Latitude and Longitude for your location and check the Timezone (Section 7/8). With Sun Schedule ON, the fixed Open/Close times are ignored. |
| Homing motor doesn't stop on its own | Expected in this version — automatic stop (StallGuard) is disabled. Press Stop when the curtain reaches the closed position (Section 5). |
| Motor driver gets hot | Lower the IRUN value. |

---

## 13. Quick Reference

**Web page controls**

| Control (web page) | Purpose |
| --- | --- |
| Ropener (cover) | Open, close, set position, or stop. |
| State | Shows IDLE / OPENING / CLOSING / HOMING. |
| Start-Stop Homing | Start or cancel calibration. |
| Open Time / Close Time | Daily schedule times (fixed-time mode). |
| Schedule Enabled | Turn the daily schedule on/off. |
| Sun Schedule | Switch between fixed-time and sunrise/sunset scheduling. |
| Latitude / Longitude | Your location used to compute sunrise/sunset. |
| Sun Open Offset / Sun Close Offset | Minutes to shift open/close relative to sunrise/sunset. |
| Timezone | Your local timezone (POSIX string). |
| Centimeters | Curtain travel distance. |
| Speed / Acceleration | Motion tuning. |
| Motor Direction | Reverse open/close direction. |
| IRUN value | Motor torque / current. |
| SGTHRS / TCOOLTHRS | Stall-detection tuning for homing. |
| SG_RESULT / TSTEP | Live readings used when tuning homing. |

**Physical buttons**

| Physical button | Action |
| --- | --- |
| Button 1 – tap | Close (or stop if moving). |
| Button 1 – hold | Close while held (stops on release and at the closed end). |
| Button 1 – seven quick taps | Start homing. |
| Button 2 – tap | Open (or stop if moving). |
| Button 2 – hold | Open while held (stops on release and at the open end). |
| Both buttons – hold 3 sec | Set current position as home (0%). |
| Button 3 – long press | Reset Wi-Fi and reboot to setup. |

---

*Valar Systems • [valarsystems.com](https://valarsystems.com)*

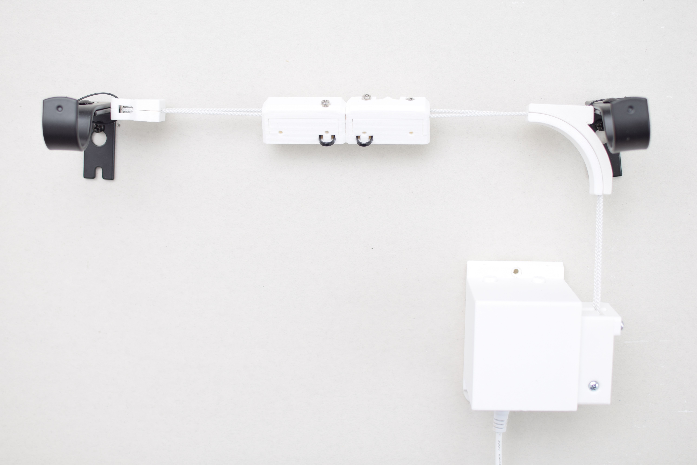
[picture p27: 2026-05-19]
media/ropener-bench-setup.jpg

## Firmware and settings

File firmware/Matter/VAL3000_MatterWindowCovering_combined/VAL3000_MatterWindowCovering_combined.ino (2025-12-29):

// Requires esp32 v3.3.5

// Matter Manager
#include <Matter.h>
// #if !CONFIG_ENABLE_CHIPOBLE
// // if the device can be commissioned using BLE, WiFi is not used - save flash space
// #include <WiFi.h>
// #endif
#include <Preferences.h>
#include <Button.h>

#include "memory.h"

MatterWindowCovering WindowBlinds;

#include "motor_control.h"

#include <ArduinoOTA.h>  // For enabling over-the-air updates


// Button callbacks

// Button1 = Top left button
// Button2 = Top Right button
// Button3 = Bottom button

// Stop movement, if moving, when button down is pressed
static void btn1PressDownCb(void *button_handle, void *usr_data) {
  Serial.println("Button pressed down");
  if (is_moving) {
    stop_flag = true;
    // set veolicty to 0 for double click?
  }
}

// Move to full close position
static void btn1SingleClickCb(void *button_handle, void *usr_data) {
  Serial.println("Button1 single click");
  if (is_moving) {
    stop_flag = true;
  } else {
    fullClose();
  }
}

// Move until stop button is pressed
static void btn1DoubleClickCb(void *button_handle, void *usr_data) {
  Serial.println("Button1 double click");
  // Create function for this?
  // Set velocity full
  // 
}

// If not moving, sets zero position
static void btn1LongPressStartCb(void *button_handle, void *usr_data) {
  Serial.println("Button1 long press click");

  if (!is_moving){

  }
  // Override position. Turn motor until button is pressed. (Set to close position once button is pressed. If this is the close direction?)
}

static void btn2PressDownCb(void *button_handle, void *usr_data) {
  Serial.println("Button2 pressed down");
  if (is_moving) {
    stop_flag = true;
  }
}

// Move to full Open position
static void btn2SingleClickCb(void *button_handle, void *usr_data) {
  Serial.println("Button2 single click");
  if (is_moving) {
    stop_flag = true;
  } else {
    fullOpen();
  }
}

static void btn2DoubleClickCb(void *button_handle, void *usr_data) {
  Serial.println("Button2 double click");
  // Move the motor until pressed to stop. Will override position
  
  // Pass bool to fulOpen to avoid
  // fullOpen(false);

}


static void btn2LongPressStartCb(void *button_handle, void *usr_data) {
  Serial.println("Button2 long press click");
}

static void btn3SingleClickCb(void *button_handle, void *usr_data) {
  Serial.println("Button2 single click");
}

// Changes the opening direction of Button1 and Button2
static void btn3DoubleClickCb(void *button_handle, void *usr_data) {
  Serial.println("Button3 double click");
  // Change direction
  if (opening_direction == 0) {
    opening_direction = 1;
    preferences.putInt("open_dir", opening_direction);
    driver.shaft(true);
  } else {
    Serial.print("Inactive");
    opening_direction = 0;
    preferences.putInt("open_dir", opening_direction);
    driver.shaft(false);
  }
}

static void btn3LongPressStartCb(void *button_handle, void *usr_data) {
  Serial.println("Button3 long press click");
  //Reset matter
  Serial.println("Decommissioning the Window Covering Matter Accessory. It shall be commissioned again.");
  WindowBlinds.setLiftPercentage(0);  // close the covering
  Matter.decommission();
}

void setup() {
  Serial.begin(115200);

  Button btn1 = Button(BUTTON_1_PIN, false);    //BUTTON_1_PIN
  Button btn2 = Button(BUTTON_2_PIN, false);    //BUTTON_1_PIN
  Button btn3 = Button(WIFI_RESET_PIN, false);  //BUTTON_1_PIN

  btn1.attachPressDownEventCb(&btn1PressDownCb, NULL);
  btn1.attachSingleClickEventCb(&btn1SingleClickCb, NULL);
  btn1.attachDoubleClickEventCb(&btn1DoubleClickCb, NULL);
  btn1.attachLongPressStartEventCb(&btn1LongPressStartCb, NULL);

  btn2.attachPressDownEventCb(&btn2PressDownCb, NULL);
  btn2.attachSingleClickEventCb(&btn2SingleClickCb, NULL);
  btn2.attachDoubleClickEventCb(&btn2DoubleClickCb, NULL);
  btn2.attachLongPressStartEventCb(&btn2LongPressStartCb, NULL);

  btn3.attachSingleClickEventCb(&btn3SingleClickCb, NULL);
  btn3.attachDoubleClickEventCb(&btn3DoubleClickCb, NULL);
  btn3.attachLongPressStartEventCb(&btn3LongPressStartCb, NULL);

  Serial1.begin(115200, SERIAL_8N1, RX_PIN, TX_PIN);  // ESP32 can use any pins to Serial

  delay(100);

  preferences.begin("local", false);

  //load_preferences();

  motor_position = preferences.getInt("motor_pos", 0); // Loads saved motor position

  travel_distance = 20; // Inches. Change this value to change the distance to openS

  // 200 steps per revolution
  
  int revolutions = travel_distance / circumference_in; // How many times the motor need to spin to reach 20 inches
  int steps_per_revolution = 200;
  maximum_motor_position = revolutions * steps_per_revolution;//
  uint8_t lastLiftPercent = ((float)motor_position / (float)maximum_motor_position) * 100;

  setup_motors();

  ArduinoOTA.begin();

  // Initialize Matter EndPoint
  // matterPref.begin("MatterPrefs", false);
  // default lift percentage is 100% (fully open) if not stored before
  // uint8_t lastLiftPercent = preferences.getUChar(liftPercentPrefKey, 100);

  // Initialize window covering with BLIND_LIFT type
  WindowBlinds.begin(lastLiftPercent, MatterWindowCovering::DRAPERY);

  // Configure installed limits for lift
  WindowBlinds.setInstalledOpenLimitLift(MIN_LIFT);
  WindowBlinds.setInstalledClosedLimitLift(MAX_LIFT);

  // Initialize current positions based on percentages and installed limits
  uint16_t openLimitLift = WindowBlinds.getInstalledOpenLimitLift();
  uint16_t closedLimitLift = WindowBlinds.getInstalledClosedLimitLift();
  currentLiftPercent = lastLiftPercent;
  if (openLimitLift < closedLimitLift) {
    currentLift = openLimitLift + ((closedLimitLift - openLimitLift) * lastLiftPercent) / 100;
  } else {
    currentLift = openLimitLift - ((openLimitLift - closedLimitLift) * lastLiftPercent) / 100;
  }

  Serial.printf(
    "Window Covering limits configured: Lift [%d-%d cm]\r\n", WindowBlinds.getInstalledOpenLimitLift(),
    WindowBlinds.getInstalledClosedLimitLift());
  Serial.printf("Initial positions: Lift=%d cm (%d%%)\r\n", currentLift, currentLiftPercent);

  // Set callback functions
  WindowBlinds.onOpen(fullOpen);
  WindowBlinds.onClose(fullClose);
  WindowBlinds.onGoToLiftPercentage(goToLiftPercentage);
  WindowBlinds.onStop(stopMotor);

  // Generic callback for Lift change
  WindowBlinds.onChange([](uint8_t liftPercent, uint8_t tiltPercent) {
    Serial.printf("Window Covering changed: Lift=%d%%, Tilt=%d%%\r\n", liftPercent, tiltPercent);
    //visualizeWindowBlinds(liftPercent, tiltPercent);
    return true;
  });

  // Matter beginning - Last step, after all EndPoints are initialized
  Matter.begin();
  // This may be a restart of a already commissioned Matter accessory
  if (Matter.isDeviceCommissioned()) {
    Serial.println("Matter Node is commissioned and connected to the network. Ready for use.");
    Serial.printf("Initial state: Lift=%d%%\r\n", WindowBlinds.getLiftPercentage());
    // Update visualization based on initial state
  }
}

void loop() {
  ArduinoOTA.handle();  // Handles a code update request

  // Check Matter Window Covering Commissioning state, which may change during execution of loop()
  if (!Matter.isDeviceCommissioned()) {
    Serial.println("");
    Serial.println("Matter Node is not commissioned yet.");
    Serial.println("Initiate the device discovery in your Matter environment.");
    Serial.println("Commission it to your Matter hub with the manual pairing code or QR code");
    Serial.printf("Manual pairing code: %s\r\n", Matter.getManualPairingCode().c_str());
    Serial.printf("QR code URL: %s\r\n", Matter.getOnboardingQRCodeUrl().c_str());
    // waits for Matter Window Covering Commissioning.
    uint32_t timeCount = 0;
    while (!Matter.isDeviceCommissioned()) {
      delay(100);
      if ((timeCount++ % 50) == 0) {  // 50*100ms = 5 sec
        Serial.println("Matter Node not commissioned yet. Waiting for commissioning.");
      }
    }
    Serial.printf("Initial state: Lift=%d%%\r\n", WindowBlinds.getLiftPercentage());
    // Update visualization based on initial state

    Serial.println("Matter Node is commissioned and connected to the network. Ready for use.");
  }

  // A button is also used to control the window covering
  // Check if the button has been pressed
  if (digitalRead(buttonPin) == LOW && !button_state) {
    // deals with button debouncing
    button_time_stamp = millis();  // record the time while the button is pressed.
    button_state = true;           // pressed.
  }

  // Onboard User Button is used to manually change lift percentage or to decommission
  uint32_t time_diff = millis() - button_time_stamp;
  if (digitalRead(buttonPin) == HIGH && button_state && time_diff > debounceTime) {
    // Button is released - cycle lift percentage by 20%
    button_state = false;  // released
    uint8_t targetLiftPercent = currentLiftPercent;
    // go to the closest next 20% or move 20% more
    if ((targetLiftPercent % 20) != 0) {
      targetLiftPercent = ((targetLiftPercent / 20) + 1) * 20;
    } else {
      targetLiftPercent += 20;
    }
    if (targetLiftPercent > 100) {
      targetLiftPercent = 0;
    }
    Serial.printf("User button released. Setting lift to %d%%\r\n", targetLiftPercent);
    WindowBlinds.setTargetLiftPercent100ths(targetLiftPercent * 100);
  }

  // Onboard User Button is kept pressed for longer than 5 seconds in order to decommission matter node
  if (button_state && time_diff > decommissioningTimeout) {
    Serial.println("Decommissioning the Window Covering Matter Accessory. It shall be commissioned again.");
    WindowBlinds.setLiftPercentage(0);  // close the covering
    Matter.decommission();
    button_time_stamp = millis();  // avoid running decommissioning again, reboot takes a second or so
  }
}

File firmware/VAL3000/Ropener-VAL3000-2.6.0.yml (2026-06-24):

# =============================================================================
# Ropener — ESPHome firmware
# Version: 2.6.0
# =============================================================================
#
# A Wi-Fi connected curtain/cover controller that pulls a poly rope using a
# TMC2209-driven stepper motor on an ESP32-C3. Control it via a browser at
# http://ropener-XXXXXX.local (where XXXXXX is the last 3 bytes of the
# device's MAC address — printed on the serial log at boot). No Home Assistant
# required. Can also pair with Home Assistant over the native ESPHome API. Supports a 0..1 position
# (closed..open), StallGuard-based auto-homing, and tunable motion/sensorless
# homing parameters.
#
# -----------------------------------------------------------------------------
# Hardware
# -----------------------------------------------------------------------------
#   MCU     : ESP32-C3 (esp32-c3-devkitm-1, esp-idf framework)
#   Driver  : TMC2209 stepper driver, single-wire UART control (PDN_UART)
#   Motor   : NEMA-17 stepper, 200 full steps/rev, 8x microstepping = 1600 steps/rev
#   Gearing : MK7 drive gear, ~3.7699 cm of rope per revolution
#
# -----------------------------------------------------------------------------
# GPIO wiring (ESP32-C3 -> TMC2209 / buttons)
# -----------------------------------------------------------------------------
#   GPIO0 : INDEX  (TMC2209 step-counter output, informational)
#   GPIO1 : DIAG   (TMC2209 StallGuard / diagnostic output -> on_stall)
#   GPIO3 : Button 2  (open),         active-low pushbutton to GND
#   GPIO4 : Button 1  (close / home), active-low pushbutton to GND
#   GPIO5 : UART RX  <- TMC2209 PDN_UART
#   GPIO6 : UART TX  -> TMC2209 PDN_UART
#   GPIO7 : Button 3  (Wi-Fi reset),  active-low pushbutton to GND
#   GPIO8 : ENN    (TMC2209 enable, active-low)
#
# -----------------------------------------------------------------------------
# Position / motion model
# -----------------------------------------------------------------------------
#   Steps are the canonical position unit. Cover position is derived live:
#
#       position = current_position / global_distance_steps      (0.0 .. 1.0)
#
#   where:
#       global_distance_steps = (distance_cm / gear_distance_cm) * steps_per_revolution
#
#   Defaults give a 30 cm travel window:
#       30 cm / 3.7699 cm/rev * 1600 steps/rev ≈ 12,732 steps
#
#   Position 0 = fully closed (rope home, located by StallGuard).
#   Position 1 = fully open   (target = global_distance_steps).
#
# -----------------------------------------------------------------------------
# Homing
# -----------------------------------------------------------------------------
#   The closed end is found by sensorless StallGuard: the motor drives toward
#   the closed direction until SG_RESULT drops below SGTHRS while the motor is
#   running below TCOOLTHRS, which fires DIAG and triggers the stepper's
#   on_stall handler. That handler stops the motor and zeroes the position.
#
#   Manual re-home (drives motor toward closed end until StallGuard fires):
#     - Tap Button 1 seven times quickly, OR
#     - Press the "Start-Stop Homing" diagnostic button.
#   Homing can be cancelled (stops the motor and zeroes the position) by:
#     - Any press of Button 1 OR Button 2 while HOMING, OR
#     - Pressing the "Start-Stop Homing" button again while HOMING.
#
# -----------------------------------------------------------------------------
# Buttons (physical, on the device)
# -----------------------------------------------------------------------------
#   Safety rules that always win, whatever the gesture:
#     - A press while OPENING/CLOSING stops the motor in place.
#     - A press while HOMING stops the motor and zeroes the position.
#   Holding a button to move only runs while held and the motor auto-stops at
#   the 0 % / 100 % end — it cannot be driven past the limit.
#
#   Button 1 (GPIO4):
#     - Tap (quick press/release)   : close cover (to 0 %)
#     - Press and hold              : close while held; auto-stops at 0 %, and
#                                     stops early on release (hold-to-run)
#     - Seven quick taps            : start homing
#   Button 2 (GPIO3):
#     - Tap (quick press/release)   : open cover (to 100 %)
#     - Press and hold              : open while held; auto-stops at 100 %, and
#                                     stops early on release (hold-to-run)
#   Button 1 + Button 2 together:
#     - Hold both for 3 s           : set the current position as home (0)
#   Button 3 (GPIO7):
#     - Long  press (3 s - 10 s)    : clear saved Wi-Fi credentials + reboot
#
# -----------------------------------------------------------------------------
# Daily schedule (browser-editable, no Home Assistant required)
# -----------------------------------------------------------------------------
#   Open the web UI and set:
#     - "Open Time"  / "Close Time" : daily times to open / close the cover
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

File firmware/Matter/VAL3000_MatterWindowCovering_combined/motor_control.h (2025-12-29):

uint16_t positionLabel;

#include <TMCStepper.h>

#include "soc/timer_group_struct.h"
#include "soc/timer_group_reg.h"

#define ENABLE_PIN 8
#define RX_PIN 5
#define TX_PIN 6
#define STALLGUARD_PIN 1
#define INDEX_PIN 0

#define BUTTON_1_PIN GPIO_NUM_3
#define BUTTON_2_PIN GPIO_NUM_4
#define WIFI_RESET_PIN GPIO_NUM_7

#define DRIVER_ADDRESS 0b00  // TMC2209 Driver address according to MS1 and MS2
#define R_SENSE 0.11f        // R_SENSE for current calc.

#define CLOSE_VELOCITY 600
#define OPEN_VELOCITY -600
#define STOP_MOTOR_VELOCITY 0

// function prototypes
void move_close(void);
void move_open(void);
void move_open(void);
void stop(void);

void position_watcher_task(void *parameter);
TaskHandle_t position_watcher_task_handler = NULL;

TMC2209Stepper driver(&Serial1, R_SENSE, DRIVER_ADDRESS);

void IRAM_ATTR stall_interrupt() {
  stall_flag = true;
}

// Interrupt tracks the position of the stepper motor using the index pin
void IRAM_ATTR index_interrupt(void) {

  if (is_closing == true) {
    motor_position++;
  } else {
    motor_position--;
  }

  // Ensure motor position stays within bounds
  if (motor_position < 0) {
    motor_position = 0;
  } else if (motor_position > maximum_motor_position) {
    motor_position = maximum_motor_position;
  }
}

int getMotorPosition() {

  return motor_position;
}

/* Enables power stage of TMC */
void enable_driver() {
  digitalWrite(ENABLE_PIN, 0);
}

/* Disabled power stage of TMC */
void disable_driver() {
  digitalWrite(ENABLE_PIN, 1);
}

void setCloseCall() {
  Serial.println("Button Pressed");
  motor_position = maximum_motor_position;
  target_percent = 100;
  Serial.print("set close position: ");
  Serial.println(target_percent);
}


/*
// Function that commands motor to move to position 
void move_to_percent100ths(uint16_t percent100ths) {
  printf("move_to_percent100ths(): %i\n", percent100ths);

  switch (percent100ths) {
    case 0:
      target_position = 0;
      break;
    case 100:
      target_position = maximum_motor_position;
      break;
    default:
      target_position = (percent100ths / 100.0) * maximum_motor_position;
      break;
  }

  //printf("target_position(): %i\n", target_position);
  //printf("motor_position(): %i\n", motor_position);
  //printf("maximum_motor_position(): %i\n", maximum_motor_position);

  if (target_position == motor_position) {
    printf("Not moving the window because it is already at the desired position\n");
    printf("target_position: %li\n", target_position);
    printf("motor_position: %li\n", motor_position);
    return;
  } else if (target_position > motor_position || percent100ths == 100) {
    move_close();
  } else if (target_position < motor_position || percent100ths == 0) {
    move_open();
  }
}



void move_close() {
  printf("move_close()\n");

  if (motor_position < 0) {
    motor_position = 0;
  }

  // printf("motor_position close: %lu\n", motor_position);    // TESTING
  // printf("target_position close: %lu\n", target_position);  // TESTING

  // printf("max_motor_position close: %lu\n", maximum_motor_position);  // TESTING
  // printf("target_percent close: %lu\n", target_percent);  // TESTING

  stop_flag = false;
  is_closing = true;
  is_moving = true;

  xTaskCreate(position_watcher_task, "position_watcher_task", 4096, NULL, 1, &position_watcher_task_handler);

  enable_driver();
  // Add for loop for acceleration
  driver.VACTUAL(CLOSE_VELOCITY);
}





void move_open() {
  printf("move_open()\n");

  if (motor_position < 0) {
    motor_position = maximum_motor_position;
  }

  printf("motor_position close: %lu\n", motor_position);    // TESTING
  printf("target_position close: %lu\n", target_position);  // TESTING

  printf("max_motor_position close: %lu\n", maximum_motor_position);  // TESTING
  printf("target_percent close: %lu\n", target_percent);              // TESTING

  stop_flag = false;
  is_closing = false;
  is_moving = true;

  xTaskCreate(position_watcher_task, "position_watcher_task", 4096, NULL, 1, &position_watcher_task_handler);

  enable_driver();
  // Add for loop for acceleration
  driver.VACTUAL(OPEN_VELOCITY);
}


*/


//////////////////////////////////////////////////////////////////////////////////////////////////////////////////////////////




// Window Covering Callbacks
bool fullOpen() {
  // This is where you would trigger your motor to go to full open state
  // For simulation, we update instantly
  uint16_t openLimit = WindowBlinds.getInstalledOpenLimitLift();
  currentLift = openLimit;
  currentLiftPercent = 100;
  Serial.printf("Opening window covering to full open (position: %d cm)\r\n", currentLift);


  /////////////////
  if (motor_position < 0) {
    motor_position = 0;
  }

  printf("motor_position close: %lu\n", motor_position);    // TESTING
  printf("target_position close: %lu\n", target_position);  // TESTING

  printf("max_motor_position close: %lu\n", maximum_motor_position);  // TESTING
  printf("target_percent close: %lu\n", target_percent);              // TESTING

  stop_flag = false;
  is_closing = false;
  is_moving = true;

  xTaskCreate(position_watcher_task, "position_watcher_task", 4096, NULL, 1, &position_watcher_task_handler);

  enable_driver();
  // Add for loop for acceleration
  driver.VACTUAL(OPEN_VELOCITY);

  return true;
}

bool fullClose() {
  // This is where you would trigger your motor to go to full close state
  // For simulation, we update instantly
  uint16_t closedLimit = WindowBlinds.getInstalledClosedLimitLift();
  currentLift = closedLimit;
  currentLiftPercent = 0;
  Serial.printf("Closing window covering to full close (position: %d cm)\r\n", currentLift);

  if (motor_position > maximum_motor_position) {
    motor_position = maximum_motor_position;
  }

  // printf("motor_position close: %lu\n", motor_position);    // TESTING
  // printf("target_position close: %lu\n", target_position);  // TESTING

  // printf("max_motor_position close: %lu\n", maximum_motor_position);  // TESTING
  // printf("target_percent close: %lu\n", target_percent);  // TESTING

  stop_flag = false;
  is_closing = true;
  is_moving = true;

  xTaskCreate(position_watcher_task, "position_watcher_task", 4096, NULL, 1, &position_watcher_task_handler);

  enable_driver();
  // Add for loop for acceleration
  driver.VACTUAL(CLOSE_VELOCITY);

  return true;
}
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

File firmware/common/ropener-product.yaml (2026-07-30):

# =============================================================================
# Ropener — product layer (curtain opener)
# =============================================================================
# The Ropener-specific behaviour that sits ON TOP of the shared valar-core +
# scheduling packages. Each board wrapper (firmware/VAL3000, firmware/VAL3100)
# includes:
#
#   packages:
#     valar_core: { url: .../valar-motion, files: [common/valar-core.yaml], ... }
#     scheduling: { url: .../valar-motion, files: [common/scheduling.yaml], ... }
#     product:    !include ../common/ropener-product.yaml
#
# This layer owns: the cover, sensorless homing, the two-button gesture UI, the
# gear/distance math, and the schedule_open/schedule_close scripts the shared
# scheduling mixin calls. It reuses core's driver (id: driver), tuning entities,
# diagnostics, and web UI groups, and renames a few core entities via !extend so
# field units keep their existing Home Assistant entity_ids.
# =============================================================================

# Mechanical + gesture constants (compile-time; a new flash to change).
substitutions:
  gear_distance_cm: "3.7699"       # MK7 drive gear: cm of rope per revolution
  steps_per_revolution: "1600"     # 200 full steps * 8 microsteps
  hold_run_ms: "700"               # press longer than this = hold-to-run
  tap_window_ms: "400"             # rapid-tap chaining window
  combo_home_ms: "3000"            # both buttons held this long = set home
  home_speed: "3000"               # homing runs at this fixed speed (above the
                                   # ~2000 drivetrain resonance; gentle into the
                                   # stop; ~14 s for a full 1 m travel)
  home_timeout_s: "60"             # homing auto-aborts after this if not stopped
                                   # -- backstops an accidental press and a
                                   # mis-tuned StallGuard that never fires

# Product boot steps. Core (priority 600) has already configured the TMC2209 and
# stepper; here we resync the derived step count and restore the saved position
# so the cover comes up accurate without a re-home. (scheduling re-applies
# tz/location at priority -100, after this.)
# The API's reboot_timeout defaults to 15 min: if no *API* client connects in
# that window the device reboots. It counts native-API clients only — a browser
# on the web UI is not one. The Ropener is sold as working without Home
# Assistant, so a customer driving it purely from the browser got a controller
# that rebooted every 15 minutes, stopping the curtain mid-travel if it happened
# to be moving. 0 = never reboot for lack of a client.
#
# Trade-off: this also removes the watchdog that recovers a wedged API
# connection. Acceptable here — the users it was rebooting are the ones not
# using the API at all — and safe_mode still covers boot loops.
api:
  reboot_timeout: 0s

esphome:
  on_boot:
    - priority: 400.0
      then:
        - script.execute: recompute_distance
        - script.execute: recompute_tcoolthrs
        - stepper.report_position:
            id: driver
            position: !lambda "return id(global_current_position);"
        - stepper.set_target:
            id: driver
            target: !lambda "return id(global_current_position);"
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

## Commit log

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2025-12-30 Refactor motor position logic and button callbacks
    Simplifies zero position setting and updates button callback logic for window covering control. Refactors motor position increment/decrement logic, removes bounds enforcement in index interrupt, and replaces target_percent with percent_open. Also updates lift calculation and related variable usage for clarity.
    [memory.h, motor_control.h]
2025-12-30 Fix motor direction logic and improve position updates
    Corrected OPEN_VELOCITY and CLOSE_VELOCITY definitions to match expected motor directions. Improved Matter position updates and logging, added PRESSDOWN_DELAY constant, and fixed logic in position_watcher_task for accurate open/close detection. Enhanced serial output for debugging and ensured Matter state is updated more frequently during movement.
    [motor_control.h]
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2025-12-30 Refactor window covering motor control and state logic
    Improved motor position handling, operational state updates, and task management for window covering control. Refactored goToLiftPercentage, fullOpen, and fullClose to better manage motor state, position limits, and Matter state reporting. Updated preferences loading defaults and fixed initialization logic. Enhanced position_watcher_task to properly suspend and resume, and improved debug output for easier troubleshooting.
    [memory.h, motor_control.h]
2025-12-30 Refactor button callbacks and motor position logging
    Improved button press handling by adjusting pressdown logic and timer placement in btn1PressDownCb and btn2PressDownCb. Commented out frequent motor position serial prints in position_watcher_task and adjusted the update interval for Matter position updates to reduce log noise.
    [motor_control.h]
2026-01-02 Update STEP and 3MF files for plastics body parts
    Refreshed hardware/plastics/body STEP files and platter-all.3mf with new timestamps and geometry changes, including updates to main-body.step entity names, schema, and geometry definitions. These changes likely reflect design revisions or corrections to the 3D models.
    [arm-connector.step, arm-left.step, arm-right.step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]
2026-01-03 Refactor and clean up Matter window covering firmware
    Renamed and refactored the LIFT variant to ESP_buttons, removing the combined and tmc variants and their associated files. Updated button handling and pin definitions in the ESP_buttons and distance 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
    [partitions.csv]
2026-01-07 Update button pin and improve motor initialization logic
    Changed the USER BUTTON pin from GPIO_NUM_4 to GPIO_NUM_7 in VAL3000_MatterWindowCovering.ino. In VAL3000_MatterWindowCovering_distance.ino, added SRAM usage considerations, improved motor initialization after Matter commissioning, removed redundant motor flag reset, and commented out some logging to optimize memory usage and commissioning reliability.
2026-01-07 Refactor firmware structure and remove Matter examples
    Deleted Matter window covering example directories and files, including source code, documentation, and CI configs. Renamed MorningRope firmware files to ropener-api and moved Matter window covering 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
    [partitions.csv]
2026-01-07 Remove partitions.csv and add delay comment in loop
    Deleted the partitions.csv file and updated ropener-matter.ino to add a comment explaining the 30-second delay before initializing the motor system after Matter device commissioning, which helps prevent crashes due to low SRAM on ESP32-C3.
    [partitions.csv]
2026-01-16 Refactor curtain hardware STEP files and firmware
    Renamed MorningRope.ino to ropener-api.ino for consistency. Replaced several curtain hardware STEP files with new versions, including new back-tab clamp and mount files, and removed obsolete back-tab-mount and ring-mount STEP files. Updated rope-right-angle and platter-all 3D model files to reflect hardware changes.
    [back-tab-clamp-left.step, back-tab-clamp-right.step, back-tab-mount-left-bottom.step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]
2026-01-17 Update right arm STEP and platter 3MF files
    Refreshed hardware/plastics/body/arm-right.step and hardware/plastics/platter-all.3mf with new geometry and metadata. This likely reflects design changes or improvements to the right arm and platter 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
    [arm-right.step, platter-all.3mf]
2026-01-21 Removed ESP32 button library
    ESP32 button library was causing issues with ESPUI library. Removed it because it required the ESPUI library to be updated which is too much work
    [motor_control.h]
2026-01-26 Fixed update percentage direction
    [motor_control.h]
2026-01-28 fixed issue where the motor does not stop if the buttons are pressed when started by Matter
    fixed issue where the motor does not stop if the buttons are pressed when started by Matter
2026-01-28 Removed fullOpen and close functions.
    Fullopen and close functions are not required and cause issues with percent open. They have been removed
    [motor_control.h]
2026-02-02 Plastic updates and ESPHome updates
    ESPhome still not working, but example is working
    [arm-left.step, arm-right.step, end-pulley-top.step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]
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2026-04-10 Fixed arms
    [arm-left.step, arm-right.step]
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2026-05-10 Fix cover position lambda and Button 1 long-press conflict
    - Cover position was integer-truncated due to float cast applied after
    division; now casts current_position to float before dividing.
    - Button 1 on_release fired before on_click, so every long-press
    inadvertently closed the cover before homing. Replaced on_release with
    a short on_click range so the close and home actions are mutually
    exclusive.
2026-05-10 Document ESPHome configuration
    Add a top-of-file overview (hardware, GPIO map, position model, homing,
    button bindings, required secrets) plus per-section documentation
    covering each global, the mechanical substitutions, the on_boot
    sequence, the stepper/StallGuard configuration, the cover position
    math, and every diagnostic/CONFIG entity with its TMC2209 register or
    field semantics.
    Also normalises indentation in `binary_sensor:` and converts the stale
    "these don't actually work" scratch comment on the cover into a clear
    explanation of why the on_opening/on_closing triggers don't fire today.
    Behaviour-only change: comments / whitespace; no functional changes.
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2026-05-22 Persist stepper position and toggle homing
    Add persistent last-known stepper position and make homing cancellable.
    - Introduces a new global (global_current_position) that is persisted and restored so the cover position survives reboots.
    - On boot, restores the stepper reported position and parks the stepper target at the restored position to avoid unwanted motion.
    - Persist the stepper current position every 200 ms from the interval task.
    - Change homing behavior: the diagnostic button is renamed to "Start/Stop Homing" and now toggles homing — pressing it while HOMING stops the motor and zeroes position, otherwise it starts sensorless homing.
    - on_stall handler updated to only treat a st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
2026-05-26 Update README with StallGuard warning and setup instructions
    Added warning about StallGuard setup and detailed instructions for configuring the device in Home Assistant, including motor settings and homing procedure.
2026-05-30 UPdated top carriage step file and platter 3mf file to reflect changes in the design. Also updated .gitignore to ignore esphome files.
    [carriage-top-right.step, platter-all.3mf]
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2026-06-24 Safer button behavior: hold-to-run, 7-tap homing, two-button set-home
    Rework the physical-button handling on both VAL3000 and VAL3100 to be
    safer around children and the elderly:
    - Tap still opens/closes, but press-and-hold now runs the motor only
    while held and stops on release. Hold-to-run targets the configured
    ends, so it auto-stops at 0%/100% and cannot be driven past them.
    - Start homing with seven quick taps of Button 1 (replaces the old
    3-10s long-press, which is now hold-to-run).
    - Hold both buttons for 3s to set the current position as home (0).
    - Any press while HOMING now stops and zeroes from either button
    (was Button 1 only). A press while moving still stops instantly.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
    [Ropener-VAL3000-2.5.0.yml, Ropener-VAL3100-2.5.0.yml]
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2026-06-26 VAL3100 hardware bring-up + Board sensor + web flasher
    - VAL3100: correct pin map to match the real board — UART TX=GPIO0,
    RX=GPIO1, DIAG=GPIO6, Button 2=GPIO19 (fixes the UART timeout / no
    motor current), and add a status LED on GPIO23.
    - Both boards: add a "Board" diagnostic sensor (VAL3000/C3 vs VAL3100/C6)
    so the right firmware can be confirmed on the right hardware.
    - Add flash/ web flasher (ESP Web Tools manifest + install page) that
    auto-selects the binary by chip family.
    - gitignore release-only *.ota.bin.md5.
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2026-06-26 Fix web flasher CORS: serve firmware bins same-origin
    ESP Web Tools' fetch() of the .factory.bin from GitHub release URLs is
    blocked by the browser — release downloads (github.com redirects and
    release-assets.githubusercontent.com) send no Access-Control-Allow-Origin
    header, so the cross-origin fetch from valar-systems.github.io fails with
    "Failed to fetch" right after the board is detected.
    Serve the bins from the Pages origin instead:
    - manifest.json now uses relative paths (Ropener-VAL3###.factory.bin)
    - pages.yml downloads the latest release's factory bins into flash/ at
    build time (keeps binaries out of git) and re-deploys on release publish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
2026-06-26 Refactor firmware into a shared core + thin per-board files
    The VAL3000 (ESP32-C3) and VAL3100 (ESP32-C6) YAMLs were ~1,750 near-identical
    lines each, differing only by chip variant, GPIO pin map, OTA asset name, and
    (C6 only) a status LED. Keeping the two in sync by hand was error-prone.
    Collapse the shared ~1,700 lines into firmware/common/ropener-core.yaml and
    reduce each board to a thin wrapper that sets its board-specific substitutions
    (board_variant, board_id, ota_asset, pin_*) and includes the core as a package.
    The VAL3100-only status LED stays in the VAL3100 file as an additive block, so
    the core has no board-specific config.
    Behaviour-preserving: `esphome config` for both boards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
2026-06-26 Bump firmware to 2.6.2
    - firmware_version 2.6.1 -> 2.6.2 in the shared core (single source of truth;
    feeds project.version and the "Firmware Version" diagnostic sensor)
    - rename per-board wrappers to Ropener-VAL3###-2.6.2.yml (filename convention)
    - gitignore ESPHome build caches under firmware/**/.esphome/
    Behaviour is unchanged from 2.6.1 (the resolved config is identical apart from
    the version string); this release exists to exercise the OTA self-update and
    web-flasher upload pipeline end to end.
2026-06-26 pages: skip (don't fail) Pages deploy for releases not cut from main
    The github-pages environment only permits deployments from the default branch.
    A release published from a feature branch runs the workflow from its tag ref,
    so actions/deploy-pages was rejected at the environment gate and the run failed
    hard. Guard the deploy job so release events only deploy when the release was
    cut from the default branch; branch-cut releases now skip cleanly (deploy from
    main on merge, or run workflow_dispatch manually).
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2026-06-28 Repo cleanup: untrack build cache, drop orphan gif, sync flasher version
    - Untrack firmware/VAL3100/.esphome build cache that leaked in before the
    .esphome gitignore rule existed (gitignore can't untrack existing files)
    - Delete orphan 2-byte main-page-gif.gif at repo root (unreferenced)
    - Bump flash/manifest.json version 2.6.1 -> 2.6.2 to match current firmware
2026-06-28 docs: make BOM single-source — parse BOM-V2.0.md instead of duplicating data
    The part data lived in two places (hardcoded rows in make_bom.py AND
    BOM-V2.0.md, "kept in sync by hand"), which drifts. Now BOM-V2.0.md is the
    single source: make_bom.py parses its headings + tables at build time and
    applies the existing Valar branding (logo, orange headers, hyperlinks, footer).
    - Add parse_bom() to read ## / ### headings and markdown tables from the .md
    - Replace the four hardcoded bom_table([...]) blocks with a render loop
    - Rewrite BOM-V2.0.md tables to the polished text the deliverable already used
    (× , en-dashes, unit spacing) so the .md is canonical and the GitHub-rendered
    table also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
2026-06-29 docs: make User Guide single-source — parse Ropener-User-Guide.md
    The full guide was duplicated: ~540 lines of hardcoded content in
    make_user_guide.py AND Ropener-User-Guide.md, hand-synced. Now the markdown is
    the single source. The script keeps its branding helpers (callout boxes, orange
    table headers, monospacing, logo, footer) and a small markdown-subset parser
    drives them: headings, paragraphs, bullet/numbered lists, fenced code, tables,
    and blockquotes. A multi-line "> ⚠️" blockquote renders as a callout box; a
    single-line "> **Label:**" renders as an inline note. The Contents TOC and the
    markdown title/footer are treated as chrome and skipped; table column widths
    (presentation)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
2026-07-12 fix(firmware): persist Motor Direction across power loss; show as a dropdown
    Motor Direction reset to its default on every power cycle. Two root causes:
    1. The template *switch* defaulted to an ALWAYS_OFF restore, so every boot
    re-ran its turn_off_action and overwrote the restored direction global.
    2. ESPHome batches preference writes (flash_write_interval, default 60s) and
    never flushes on an abrupt power loss, so even a correctly-set value was
    lost when the user unplugged within that window — exactly the install/
    mounting flow where you flip direction and immediately re-power.
    Replace the switch with a `select` that mirrors global_stepper_direction as the
    single source of t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
2026-07-12 fix(firmware): persist OTA updates across power loss (add safe_mode)
    ESPHome enables ESP-IDF app-rollback by default on esp-idf
    (enable_ota_rollback defaults to True -> CONFIG_BOOTLOADER_APP_ROLLBACK_ENABLE),
    so a freshly OTA'd image boots as PENDING_VERIFY and the bootloader reverts it
    to the previous slot on the next reset unless the firmware marks it valid. The
    only ESPHome component that marks it valid is `safe_mode`, which this
    hand-written config omitted. Result: every OTA update — including the "Update
    Firmware (GitHub)" button — silently rolled back to the old version on the
    first power cycle.
    Add `safe_mode:`. It calls esp_ota_mark_app_valid_cancel_rollback() ~1 min
    after a hea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
2026-07-20 Rewire: consume valar-core + scheduling as remote packages (verify branch)
    Prove-out of the shared-core rewire (not for merge yet). Replaces Ropener's
    self-contained board core with the shared valar-core + scheduling packages from
    Valar-Systems/valar-motion, keeping only the Ropener product layer
    (cover, sensorless homing, two-button gesture UI, gear math, and the
    schedule_open/schedule_close scripts the scheduling mixin calls).
    - firmware/common/ropener-product.yaml — the product layer; renames core's
    shared entities via !extend so field units keep their HA entity_ids
    (IRUN value, SGTHRS value, TCOOLTHRS value, SG_RESULT Sensor, TSTEP Sensor,
    WiFi Reset)
    - firmware/VAL3000|VAL3100/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
    [ropener-product.yaml]
2026-07-20 Ship rewire: retire self-contained core, consume valar-core v0.2.0
    Make the valar-core rewire the canonical Ropener firmware:
    - delete firmware/common/ropener-core.yaml and the old per-board wrappers
    - Ropener-VAL3000.yml / Ropener-VAL3100.yml now pull valar-core + scheduling
    from Valar-Systems/valar-motion pinned to tag v0.2.0, + ropener-product.yaml
    - bump fw_version 2.6.4 -> 2.7.0
    - replace the verify workflow with build-release.yml: builds every board and,
    on a tag, attaches factory.bin + ota.bin + ota.bin.md5 with the stable
    Ropener-VAL3000 / Ropener-VAL3100 asset names (the md5 the OTA button needs)
    Verified on real hardware against the identical core commit (v0.2.0 = bc869f7):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
2026-07-21 Restore Ropener stall handling lost in the valar-core rewire (v2.7.0 regression) (#34)
    * fix(firmware): restore Ropener stall handling lost in the valar-core rewire
    v2.7.0 rewired onto valar-core as a remote package. The entity list came
    through clean, so it shipped -- but the product's on_stall handler had been
    silently replaced by core's default, which zeroes the stepper position on
    EVERY stall.
    Two live bugs resulted:
    * The device wedged in HOMING. start_homing sets global_state=3 and nothing
    cleared it, so after any home the State sensor read HOMING forever, the
    cover stayed CLOSING, every button gesture died (all guard on state==0)
    and the schedule refused to run (guard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
    [ropener-product.yaml]
2026-07-21 feat(firmware): derive TCOOLTHRS from Speed, and surface StallGuard arming
    StallGuard only reports while TSTEP <= TCOOLTHRS, and TSTEP is inversely
    proportional to velocity. Measured on VAL3000 hardware (microsteps=8), within
    1% from Speed 3000 to 9000 under real curtain load:
    TSTEP ~= 374000 / Speed
    So the shipped default TCOOLTHRS=100 arms only above Speed ~3740. Below that
    StallGuard is switched off entirely -- no error, no log line, nothing in the UI
    -- and sensorless homing simply never completes. A customer reaches that state
    just by dragging the Speed slider down for a quieter curtain. It is also what
    made a bench unit at Speed 1500 look broken while the same firmware worked at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
    [ropener-product.yaml]
2026-07-22 feat(firmware): v2.8.0 — manual homing, StallGuard opt-in, friendly Motion Tuning
    Make the Ropener usable without StallGuard tuning, and hide the hard parts.
    Homing (safety-critical):
    - Default homing is now manual via the existing Start-Stop button. It drives
    closed at Speed 3000 (home_start), and a second press at the closed end sets
    home (home_finish). No chip stall is required.
    - 60 s abort timeout (home_timeout -> home_abort) protects against an accidental
    press: it stops and holds at the current position WITHOUT setting a new zero.
    - Button-1 x7 gesture rerouted to home_start.
    StallGuard demoted to opt-in:
    - New "StallGuard Enabled" switch, default OFF. on_stall is gated on i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
    [ropener-product.yaml]
2026-07-22 flash: bump manifest to 2.8.0
    Serve v2.8.0 (manual homing, StallGuard opt-in, friendly Motion Tuning) from
    the flasher. Also redeploys Pages via the flash/** path trigger, since the
    release-published deploy has failed the github-pages env gate every release.
2026-07-28 docs(wiki): foam mounting, M3x15 arm screw, M3x35 arm assembly screws + third clamp nut
    Build-Guide mirror: replace 3M Command Strips (x4) with five 1" foam
    mounting squares (wipe clean/dry, press firmly); correct the arm-screw
    prose 12 -> 15 mm; correct the arm-attach and bottom-join prose 30 -> 35 mm;
    document the third M3 square nut seated in one arm's pocket (must go in
    before the arms mate) that the M3 x 35 mm screw clamps into against the
    drive pulley.
2026-07-28 docs(bom): foam mounting x5, M3x15 arm screw, 3 body square nuts, 24V adapter, store links
    BOM-V2.0 (the .docx source of truth): replace command strips with five 1"
    foam mounting squares; correct the Body Assembly arm screw 16 -> 15 mm;
    raise the Body Assembly M3 square nut count 1 -> 3 (curtain stays 1, total 4);
    change the power adapter to 24 V 1.5 A (drops the stale "12 V is best" note);
    point every purchasable row at the Valar Systems store and remove all Amazon
    affiliate links. Links stay in the Description column so make_bom.py renders
    them as hyperlinks; its intro line updated to say "Valar Systems store."
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2026-07-28 docs(wiki): sync repo mirror with live-wiki edits
    Bring the docs/wiki-* mirror up to the live wiki's own edits so the mirror
    is the single source of truth: adopt the redesigned Home (and change its
    "command strips" line to foam mounting squares), the Firmware-Guide select:
    edit, and the de-emojified sidebar.
2026-07-28 docs(wiki): correct stale MK7 -> MK8 gear in Firmware-Guide
    Caught during the wiki sync sweep: the firmware overview still described the
    v1.0 MK7 gear. v1.1 ships the MK8 (matches BOM-V2.0 and Build-Guide).
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2026-07-28 docs: thread-forming M3x10 total = 22 (Body 8 / Curtain 14); drop wire nail
    Owner-confirmed: 22 thread-forming screws total. BOM-V2.0 Curtain 11 -> 14
    (Body stays 8: 4 PCB + 4 wall-plate; the 2 motor-mount screws are machine
    screws into the motor, not thread-forming). Wiki quick-BOM aggregate 23 -> 22.
    Wire nail removed from the BOM Mounting Hardware — no longer included in the kit.
2026-07-30 firmware: add "Swap Buttons" toggle (reverse on-device open/close roles)
    For mirror-image installs (pull-rope on the left instead of the right) where
    the unit sits flipped and the two buttons feel reversed. Default OFF keeps the
    shipped layout (Button 1 = close, Button 2 = open); ON makes Button 1 open and
    Button 2 close.
    The handlers are now role-symmetric: each button reads btn_swap to decide
    whether it is the close button (deferred single-tap close + 7-tap homing gesture)
    or the open button (immediate open). So the 7-tap homing gesture always follows
    the CLOSE button — Button 2 gains its own tap counter (b2_tap_count /
    b2_last_tap_ms) and a b2_tap_commit script for when it closes. Stop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
    [ropener-product.yaml]
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2026-07-30 firmware: make "Swap Buttons" a select (match Motor Direction UI)
    Per the sibling install-orientation setting, convert the toggle from a template
    switch to a template select with named states ("Normal" / "Swapped ↔"), sitting
    right under Motor Direction in Setup. Like Motor Direction it holds no state of
    its own: it reads/writes a persisted global (global_btn_swap) and never fights
    the restored value. Behaviour is identical to the switch version.
    Verified: esphome config valid, compiles clean, OTA-flashed to VAL3000 @ .58 --
    device boots with 'Swap Buttons' select showing "Normal".
    [ropener-product.yaml]
2026-07-30 docs: reconcile BOM + Build Guide with v1.2.1 hardware (items 1,2,5,7)
    - Zip tie: BOM 1 -> 4, with the breakdown in Description (1 motor-side elbow,
    1 far-side pulley, 2 ring-curtain carriages) so it matches the wiki's 4.
    - Version: BOM header "v1.1" -> current "v1.2.1"; wiki "New in v1.1" banner ->
    "Current hardware - v1.2.1" and its print-path link fixed
    (hardware/plastics/v1.1 was a broken path; the folder is v1.2.1).
    - Foam mounting row: "Foam mounting squares (set of 5) | 5" was ambiguous
    (5 sets vs 5 squares) -> "Foam mounting square, 1\" | 5" + "five squares per
    unit", in both files.
    - Carriages: added a note to both files stating the standard build uses two
    carriages, wit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
2026-07-30 docs: item 4 — add 1.5 mm hex (MK8 drive-gear set screw)
    Owner-confirmed: the MK8 drive gear is locked to the motor shaft with a set
    screw driven by a 1.5 mm hex. The wiki already listed three tools; this adds the
    missing pieces so BOM, wiki tool list, and steps agree:
    - BOM "Assembly Tools Required": add "Hex driver, 1.5 mm" (store link TODO — no
    verified 1.5 mm product URL yet).
    - Build Guide Step 4: was "fit the drive pulley onto the shaft" with no set-screw
    mention; now "fit the MK8 drive gear and secure it with its set screw (1.5 mm
    hex)", snug-then-fine-tune. Renamed pulley -> gear to match the BOM.
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
